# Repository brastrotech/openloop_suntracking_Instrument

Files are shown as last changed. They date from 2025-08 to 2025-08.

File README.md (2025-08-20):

# openloop_suntracking_Instrument
Open-loop sun tracking platform using Raspberry Pi Pico (MicroPython) and Arduino Uno (C++). Calculates sun position via GPS and astronomical algorithms for automated sun-photometer alignment. Includes code, wiring, and sensor integration.

# Open-Loop Sun Tracking Instrument

This project implements an open-loop sun tracking platform using Raspberry Pi Pico (MicroPython) and Arduino Uno (C++). It automatically calculates and aligns a sun-photometer to the sun for atmospheric or AOD studies.

## Features

- **Real-time sun position calculation** using GPS data and astronomic algorithms
- **Dual microcontroller architecture**: Pico handles GPS and sun position; Arduino manages motion and stabilization
- **Servo motor control** for pan/tilt alignment
- **IMU feedback** for basic correction (open-loop)

## Hardware

- Raspberry Pi Pico (RP2040)
- Arduino Uno
- GPS module (NEO-6M / 7m /8m)
- IMU sensor (MPU6050)
- Servo motors (e.g., MG995)
- Power: 5V regulated (e.g., LM2596, 10,000mAh Li-ion packs)

## Code Structure

- `pico_gps_suntracker.py` — MicroPython program for Pico
- `arduino_suntracker.ino` — Arduino code for Uno

## Wiring

- Pico UART TX/RX <-> Arduino UART RX/TX (with proper voltage matching if needed)
- GPS to Pico UART1
- MPU6050 to Arduino (I2C)
- Servos to Arduino PWM pins

## Usage

1. Upload each code file to its respective platform.
2. Assemble hardware per schematic in documentation.
3. On power-up, system will auto-align to the sun based on GPS and real-time computation.

---

**For circuit diagrams, theory, and advanced notes, refer to the `Design-and-development-of-openloop-suntracking-instrument.pdf` file in this repo.**

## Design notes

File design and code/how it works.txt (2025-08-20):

hey guys Yogeshkumar A. patel here
i tried to make solar tracker based on accelerometer (my work on magnetometer still in progress)
over all it is my master's report on my work of 12 months (obviously i did not work contineously as i studied). I personally used lot's of the sensors ,motors , modules ,boards my report of my project is not just how i make it all but also why make it with that component .

let's set it up!!!

1) take one arduino as shown in image here we use arduino as a mster which get the data using uart from raspberry pi pico (data means outout of the solar tracker algorithm inthe form of azuimuth and elevation  ) and using the data of the accelerometer it gives us the pitch roll which we can take as the azimuth and elevation after giving some of the calibration ....
here pitch and roll gives us two kind of banifites 1st is the we can know the data of the where the sun is and second is about to make the whole system stable ( gimbal ) here we can add gyroscope also but over all the data fusion given by that system will be more accurate as well as complex which directly affects over response time of overall system. here we use very low power boards so over all our power consumption will be lesser but it comes with certain limitation of computation power .

2)do  the same thing with the raspberry pi pico 2040 (please make sure that rspberry pi pico had all necessarry files ) check all files and collection use fake files to check the code and result you can compare the result with the website "https://gml.noaa.gov/grad/solcalc/" (the algorithm thanks to this web site "https://levelup.gitconnected.com/python-sun-position-for-solar-energy-and-research-7a4ead801777")

3)i intigrate gps with that system and communicate with uart please make sure that i choose pins according to my boards please make sure the discription of your board and connect the pin accordingly.

4) calibration of the whole system can be achived by set the both motors at 0 angle and mke them to look at the north direction we also need to check that sensor should mount on the right way

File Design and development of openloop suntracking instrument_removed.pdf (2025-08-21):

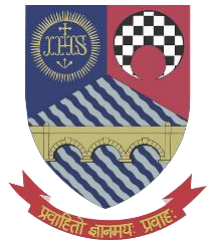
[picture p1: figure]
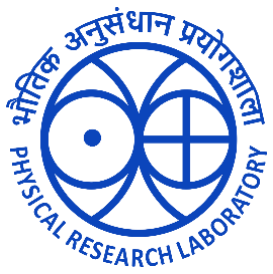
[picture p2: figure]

# DESIGN AND DEVELOPMENT OF OPEN-LOOP SUN TRACKING INSTRUMENT

This research project is accomplished, with affiliation to

### Physical Research Laboratory

By,

Yogeshkumar Patel

In the partial fulfillment of the requirements for the degree

Masters of Science in Physics

(St. Xavier’s College, Ahmedabad)

Under the guidance of

Dr. Harish Gadhavi

Space and Atmospheric Sciences Division

Physical Research Laboratory, Navrangpura Campus– Ahmedabad

Jan 22’ - Apr 23’

# Declaration

I hereby declare that this written submission represents my own work in my own words and where others’ ideas or words have been included, I have adequately cited and referenced the original sources. I also declare that I have adhered to all principles of academic honesty and integrity and have not misrepresented or fabricated or falsified any idea/data/fact/source in my submission. I understand that any violation of the above can cause disciplinary action by the Institute and can also evoke penal action from the sources which have thus not been properly cited or from whom proper permission has not been taken when needed.

Yogeshkumar A. Patel

Date: _______________

# Acknowledgments

I am very thankful to my mentor Dr. Harish Gadhavi, scientist at Physical Research Laboratory, Navrangpura - Ahmedabad for encouraging me greatly in my learning phase and guiding me for the project.

I am very grateful to Mr. Malaidevan, Physical Research Laboratory, Navrangpura- Ahmedabad for always helping me solve my queries and motivating me to keep moving forward.

I would also like to thank Dr. Rajesh Iyer, Head of the Department of Physics-Electronics, St. Xavier’s College, and Mr. Tejas Turakhia for always encouraging me and providing support whenever required for this project.

I would like to thank Parth Dineshkumar Patel for his support in the related software-related guidance.

I am also very thankful to my parents who have always believed in me throughout this journey and have always provided me their great support and encouragement which has constantly pushed me further to cross my limits and to give my best to achieve new things.

# Abstract

Aerosol optical depth (AOD) is an important measure of the amount of aerosols, such as dust, smoke, and pollution, in the Earth's atmosphere. It is defined as the amount of light that is absorbed or scattered by aerosols in the atmosphere, relative to the amount of light that would be transmitted through a clear atmosphere. AOD has several important implications for climate and environmental studies. Sun-photometer is required to estimate AOD which in turn requires it to be pointed toward Sun. We have the sun photometer which can be pointed toward Sun manually but for automated operation and to make observations from a platform such as a balloon or ship, an automated sun-tracker is required. We have tried to make a modular platform for the sun tracker which can take the readings automatically. For this purpose we used microcontroller boards Raspberry pi pico as well as Arduino UNO and for the programming purpose we used two different languages first is C++ and second is Micropython. The sun-tracker included sensors and devices such as Li-Ion cells, Buck converter, GPS, Servo motors, Accelerometer modules, etc. We aim to make a sun tracker for Sun-photometer which is having a field of view of 2.5º.

## Table of Contents

# Introduction

An essential metric for measuring how much an atmospheric aerosol affects weather, climate, and quality of air is called aerosol optical depth (AOD). The ratio of the amount of solar radiation scattered and absorbed by aerosol particles to the amount of solar radiation that would be scattered and absorbed if the atmosphere were entirely clean is known as the aerosol optical depth, or AOD [1] .
A sun tracker instrument is necessary to correctly measure AOD. Sun trackers are gadgets that measure the quantity of direct and dispersed sunlight reaching the ground by tracking the sun's position in the sky throughout the day. Sun trackers are equipped with a solar sensor that monitors the strength of solar radiation and a motorized mount that rotates the sensor to keep it aimed at the sun [2]. Suntracker data can be utilized to calculate the AOD by monitoring the difference between direct and dispersed solar radiation [3]
. Sun trackers are widely utilized in a variety of applications, including air quality monitoring, climate research, and weather forecasting [4]

AOD is a critical measure for determining the effect of atmospheric aerosols on climate change, weather patterns, and human health. Aerosols are microscopic particles floating in the atmosphere that can be solid or liquid and can come from both natural and man-made sources. By reflecting or absorbing sunlight, these particles can have a major influence on the Earth's energy balance, changing the quantity of solar radiation reaching the Earth's surface [5]. The quantity of solar radiation scattered and absorbed by aerosol particles is computed as the ratio of the amount of solar radiation scattered and absorbed if the atmosphere were fully clean [1]. The higher the AOD value, the more aerosols there are in the atmosphere and the greater their influence on climate change and air quality. AOD is commonly measured at various wavelengths using special devices such as sunphotometers or lidars [6]
. Sun trackers are essential for monitoring AOD because they offer reliable readings of direct and dispersed sunlight throughout the day. Sun trackers come in a variety of configurations, including single- and dual-axis models, and are used to follow the sun's passage across the sky [2]. A single-axis sun tracker tracks the sun's daily movement from east to west, whereas a dual-axis sun tracker tracks the sun's elevation angle [7]. Because the amount of dispersed light in the atmosphere fluctuates with the location of the sun and changes during the day, this sort of equipment is required [8]. AOD is measured using a variety of approaches, including satellite-based observations, ground-based sunphotometers, and lidars [9]. Each strategy has advantages and limitations, and the method used is determined by the unique application and data needs [10]
. Sun trackers are crucial for reliable ground-based AOD measurements, especially in densely populated regions with high levels of air pollution, where the amount of dispersed light can be significantly greater than in rural settings [11] .
Sun trackers are used for a number of purposes, such as air quality monitoring, climate research, and weather forecasting. AOD measurements can assist identify the origins of air pollution, estimating the impact of wildfires, and tracing the movement of dust and smoke plumes in air quality monitoring [12]. AOD observations may be utilized in climate research to investigate the influence of aerosols on the Earth's energy balance, cloud formation, and precipitation patterns

[13]
. AOD measurements in weather forecasting can assist enhance the accuracy of short-term weather predictions as well as identify the presence of fog or haze, which can impair aviation safety [14]

Finally, Aerosol Optical Depth is an important measure for determining the influence of atmospheric aerosols on air quality, climate, and weather patterns. Sun trackers, which follow the sun's position in the sky and measure the quantity of direct and dispersed sunlight reaching the ground, are required for reliable AOD readings. Sun trackers are widely utilized in a variety of applications, including air quality monitoring, climate research, and weather forecasting. Further study is needed to better understand the influence of atmospheric aerosols on climate change and human health, as well as to create novel AOD measurement technology.

# Theory

Greenwich Mean Time is the yearly average (or 'mean') of the time each day when the Sun crosses the Prime Meridian at the Royal Observatory Greenwich. So from that we can know about the universal time or GMT (as there is no difference between that).

greenwicℎtime = ℎour − timezone + (

minute
60 ) + (

second
3600 )

From that we got GMT or UT the second quantity is day number here we calculate according to below equation

daynum = 367 ∗ year −

7 ∗ year +

montℎ + 9
12
4

+ 275 ∗ (

montℎ
9

) + day − 730531.5

+

greenwicℎtime
24
here day number is calculated according to the above equation. The term (M+9)/12 in the formula for the Julian Day Number is used to adjust the calculation for the fact that the year in the Julian calendar starts on March 25th, not January 1st as it does in the Gregorian calendar which is the calendar system in use today.

The factor of 275*month/9 is used to account for the varying rate at which the Sun moves along the ecliptic throughout the year. Here 730531.5 is the day number of 1st January, 2000 (J2000) for the reference of the J2000.

Latitudes are horizontal lines that measure the distance north or south of the equator. Longitudes are vertical lines that measure east or west of the meridian in Greenwich, England. We can estimate the sun’s mean longitude it means the geocentric celestial longitude which the sun would have if its apparent annual motion in the ecliptic were at a uniform average or mean angular velocity.

meanlongitude = daynum ∗ 0.01720279239 + 4.894967873

mean longitude of the sun can be get by this equation here 4.894967873 represent the longitude at the J2000 and 0.01720279239 represents the mean daily motion of the sun along ecliptic.

In celestial mechanics, the mean anomaly is a parameter that describes the position of a planet or other celestial object in its orbit around the Sun. It is defined as the angle between the perihelion (the closest point in the orbit to the

Sun) and the current position of the object, measured concerning the center of the elliptical orbit.

meananomaly = daynum ∗ 0.01720197034 + 6.240040768

Here 0.01720197034 is the term that represents the daily motion of the sun in its orbit in radiance. Here 6.2400407680 is the corresponding anomaly to j2000.

The sun's ecliptic longitude is defined as the angle subtended at the earth between the vernal equinox and the sun.

Eclipticlongitude
= meanlongitude + 0.03342305518 ∗ sin(meananomaly) + 0.0003490658504 ∗ sin (2 ∗ meananomaly)

Here 0.03342305518 represents the longitude of the ascending node of the lunar orbit on January 1, 2000.

the obliquity of the ecliptic is the tilt of the earth’s axis of spin as measured from the plane of the ecliptic this angle is about 0.409 radiance and it changes every day due to various factors such as gravitational interactions with other celestial bodies and the precession of the Earth's axis.

Obliquity = 0.409877234 − 6.981317008 ∗ 10⁻⁹ ∗ daynum

The right ascension of a celestial object is a measure of its position in the sky relative to the vernal equinox, which is the point on the celestial sphere where the ecliptic intersects the celestial equator at the beginning of spring in the Northern Hemisphere.

ascension = tan⁻¹ (cos
(Obliquity) ∗ sin(Eclipticlongitude) cos(Eclipticlongitude)

)

Declination is an astronomical term that refers to the angular distance of a celestial body north or south of the celestial equator. The celestial equator is an imaginary line on the celestial sphere that represents the projection of the Earth's equator into space. Declination is measured in degrees, minutes, and seconds of arc, and it is used to locate celestial objects in the sky relative to the celestial equator.

Declanation = sin⁻¹
(sin(Obliquity) ∗ sin(Eclipticlongitude))

Sidereal time is a system of timekeeping used by astronomers to measure the position of celestial objects in the sky. It is based on the rotation of the Earth on its axis relative to the stars, rather than relative to the Sun as in solar time.

Hourangle = Siderealtime − ascension

Coordinates of the sun can be given by the following equations

Elevation = sin⁻¹
(sin(Declanation) ∗ sin(observer

′
slatitude) + cos(Declanation) ∗ cos(observer

′
slatitude) ∗ cos(Hourangle))

Azimutℎ = tan⁻¹

(−cos(Declanation) ∗ cos(Observerslatitude) ∗ sin(Hourangle)) (sin(Declanation) − sin(Observer

′slatitude) ∗ sin(Elevation))

Here the values of Azimuth and Elevation are in radiance.

# Instrumentation

To track the sun using an open loop algorithm, one needs the date, time and coordinates of the device Which we aimed to obtain using GPS. We used microcontroller board named Raspberry Pi Pico 2040 which works on Firmware MicroPython v1.19.1 to process the GPS data.

The Raspberry Pi Pico 2040 which is a microcontroller board designed by the Raspberry Pi Foundation, is based on the RP2040 microcontroller, which is a dual-core Arm Cortex-M0+ processor with 264KB of RAM. The board also features 26 GPIO pins, including 3 analog input pins, a programmable LED, and various other features.

The 26 GPIO pins on the Pico 2040 are labeled GP0 to GP25 and can be used for digital input or output. These pins can be configured as either INPUT or OUTPUT and can also be used for PWM, interrupts, and other functions. Additionally, three of these pins (GP26, GP27, and GP28) can be used for analog input, allowing the Pico 2040 to read analog voltage levels between 0 and 3.3 volts. The analog voltage input is converted into a digital value using a 12-bit ADC built into the RP2040 microcontroller.

The Pico 2040 features a clock frequency of 133 MHz, which is significantly faster than the 16 MHz clock frequency of the Arduino Uno. This means that the Pico 2040 can perform operations and execute instructions much more quickly than the Uno. However, the higher clock frequency also means that the Pico 2040 may consume more power and generate more heat than the Uno.

The Pico 2040 also includes a variety of other features, including a programmable LED connected to GP25, a reset button, and various power and ground pins. The board can be powered by a USB-C connector, and it can also be programmed and powered through its SWD (Serial Wire Debugging) port.

One of the unique features of the Pico 2040 is its support for MicroPython and CircuitPython, which are high-level programming languages designed for microcontrollers. These languages allow developers to write code in Python, which is a popular and easy-to-learn programming language. The Pico 2040 also supports C and C++ programming languages, making it a versatile platform for a wide range of projects.

Here's a brief overview of the pins on the Raspberry Pi Pico:

There are 26 GPIO pins in total, labeled GPIO0 to GPIO25, that can be configured for various purposes, such as digital input/output, analog input, and PWM.

There are three analog pins on the Raspberry Pi Pico: GP26, GP27, and GP28. These pins can be used as analog inputs to read voltages from sensors and other analog devices.

UART is a serial communication protocol that allows two devices to communicate with each other. The Raspberry Pi Pico has two UART interfaces: UART0 and UART1. The pins for UART0 are GP0 (TX) and GP1 (RX), while the pins for UART1 are GP4 (TX) and GP5 (RX).

I2C is a serial communication protocol that allows multiple devices to communicate with each other using only two wires. The Raspberry Pi Pico has two I2C interfaces: I2C0 and I2C1. The pins for I2C0 are GP8 (SDA) and GP9 (SCL), while the pins for I2C1 are GP16 (SDA) and GP17 (SCL).

SPI is a serial communication protocol that allows high-speed data transfer between devices. The Raspberry Pi Pico has two SPI interfaces: SPI0 and SPI1. The pins for SPI0 are GP10 (MOSI), GP11 (MISO), and GP12 (SCK), while the pins for SPI1 are GP19 (MOSI), GP20 (MISO), and GP21 (SCK).

There are several other pins on the Raspberry Pi Pico that can be used for various purposes, including PWM, interrupt handling, and more. These pins include GP2, GP3, GP6, GP7, GP13 to GP15, GP18, GP22 to GP25, and RUN.

The temporal resolution of the Raspberry Pi Pico 2040 depends on the specific application and how it is programmed. The RP2040 microcontroller has a built-in timer system that can be configured to generate interrupts at specific intervals. The timer system can be used to measure time intervals, generate pulses, or trigger events based on specific time conditions.

The Pico 2040's clock frequency of 133 MHz allows for very precise timing, with a maximum resolution of approximately 7.5 nanoseconds per clock cycle. This means that the microcontroller can perform many operations and execute many instructions in a very short amount of time, allowing for high-speed applications.

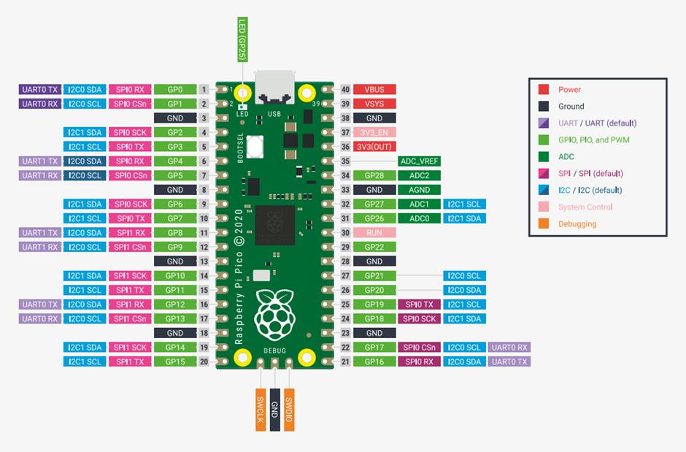
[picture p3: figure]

However, the temporal resolution of the Pico 2040 is ultimately determined by the programming language and algorithms used to control the microcontroller. For example, if the microcontroller is programmed to read a sensor value at a specific rate, the temporal resolution will depend on how accurately the timer system can be configured to trigger the sensor readings.

In general, the Pico 2040 is capable of high-speed and high-precision timing, making it well-suited for applications that require accurate timing or fast data acquisition. However, achieving optimal temporal resolution requires careful programming and configuration of the microcontroller's timer system.

GPS, or Global Positioning System, is a satellite-based navigation system that provides location and time information anywhere on or near the Earth where there is an unobstructed line of sight to four or more GPS satellites.

The GPS system consists of a network of at least 24 satellites orbiting the Earth, as well as ground control stations and GPS receivers. Each satellite broadcasts a signal containing information about its location and the current time. GPS receivers on the ground receive these signals and use the information to calculate their location and time.

To determine its location, a GPS receiver compares the time the signals were transmitted by the satellites with the time the signals were received. The time

Fig 1 :- Pin diagram of raspberry pi pico 2040 difference between when the signal was transmitted and when it was received gives the GPS receiver an estimate of the distance to each satellite. By combining the distances to at least four satellites, the GPS receiver can then calculate its location using a process called trilateration.

The GPS system also uses a technique called "differential GPS" to improve accuracy. This involves comparing the GPS signal from a stationary receiver at a known location with the GPS signal from a mobile receiver. The difference in the two signals can be used to correct errors in the GPS signal caused by atmospheric effects and other factors.

Overall, GPS is an incredibly useful technology that has a wide range of applications, from navigation and surveying to tracking and monitoring.

The GPS NEO 6M is a common GPS module used in many applications, such as drones, robotics, and navigation systems. The NEO 6M module works by receiving signals from GPS satellites and processing them to determine the user's location.

The NEO 6M module has a built-in receiver chip that is capable of receiving signals from up to 22 GPS satellites simultaneously. The module also includes an onboard microcontroller that processes the satellite data and provides a variety of output formats, including NMEA, binary, and u-blox.

The NEO 6M module communicates with a microcontroller or other host device using a serial interface and provides information such as latitude, longitude, altitude, speed, and time. The module also includes a backup battery that allows it to retain satellite data and provide faster location fixes upon power-up.

The NEO 6M module is known for its low power consumption, making it suitable for use in battery-powered applications. It is also relatively easy to use, with a simple command set that allows users to configure the module for their specific application. Overall, the NEO 6M is a popular and reliable GPS module that is widely used in many different types of projects.

Here we got the position of the sun but that data will be inside the Raspberry Pi Pico for transmitting this data to the Arduino Uno we need to establish communication between both of them here are the details about Arduino Uno.

Arduino Uno is a popular open-source microcontroller board designed for easy prototyping of electronic projects. It is based on the ATmega328P microcontroller and has 14 digital input/output pins, 6 analog inputs, and a 16 MHz quartz crystal oscillator.

Here's | a | breakdown | of | the | pins | on | the | Arduino | Uno:

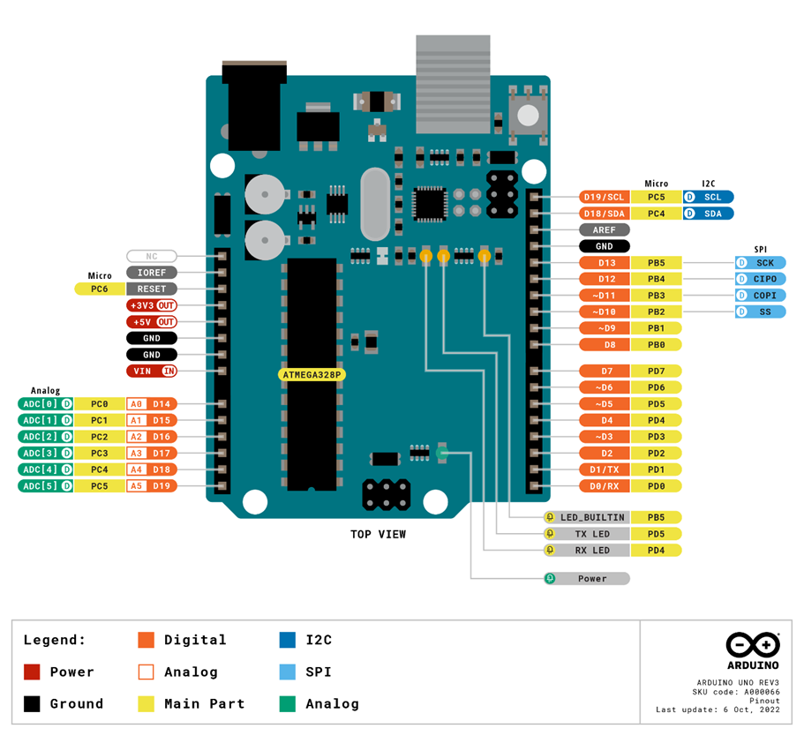
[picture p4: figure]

Digital pins (D0-D13): These are general-purpose input/output (GPIO) pins that can be used for digital input or output. They can be configured as either INPUT or OUTPUT and can also be used for PWM (pulse width modulation) and interrupts. D0 and D1 are also used for serial communication (RX and TX, respectively).

Analog pins (A0-A5): These are analog input pins that can read analog voltage levels between 0 and 5 volts. They can also be used as digital input/output pins (A0 is equivalent to D14, A1 is equivalent to D15, and so on).

Power pins: The Arduino Uno has several power pins, including a 5V pin that can provide up to 500mA of current, a 3.3V pin that can provide up to 50mA, and a Vin pin that can be used to power the board using an external power source (6-20V DC).

Fig 2 :- Pin diagram of Arduino Uno

Ground pins: The Arduino Uno has several ground pins that are connected to the board's ground plane.

Reset pin: This is a special pin that can be used to reset the microcontroller.

ICSP header: This header provides access to the ATmega328P's SPI (Serial Peripheral Interface) pins, which can be used for programming and debugging the microcontroller.

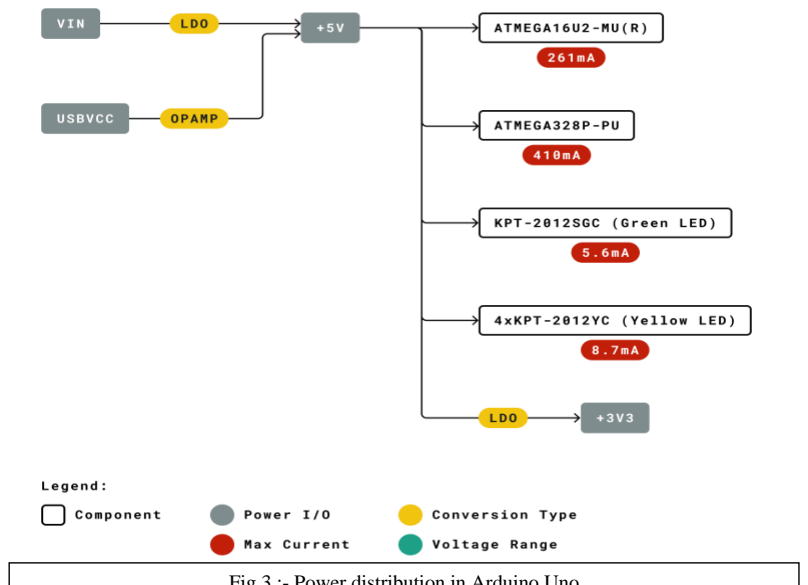
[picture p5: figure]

AREF pin: This pin can be used to set the analog reference voltage used by the analog inputs.

In addition to the above pins, the Arduino Uno also has a built-in LED connected to pin 13, which can be used for debugging and simple output. The board also has a USB connector that can be used for programming and power, as well as a barrel jack connector for external power.

Analog pins on the Arduino Uno are input pins that can read analog voltage levels between 0 and 5 volts. These pins are labeled A0 to A5 and can also be used as digital input/output pins, with A0 equivalent to D14, A1 to D15, and so on.

Analog pins on the Arduino Uno work by converting an analog voltage input into a digital value. This is done using an analog-to-digital converter (ADC) built into

Fig 3 :- Power distribution in Arduino Uno the microcontroller. The ADC samples the voltage at the analog pin and converts it into a digital value, which can then be read by the microcontroller.

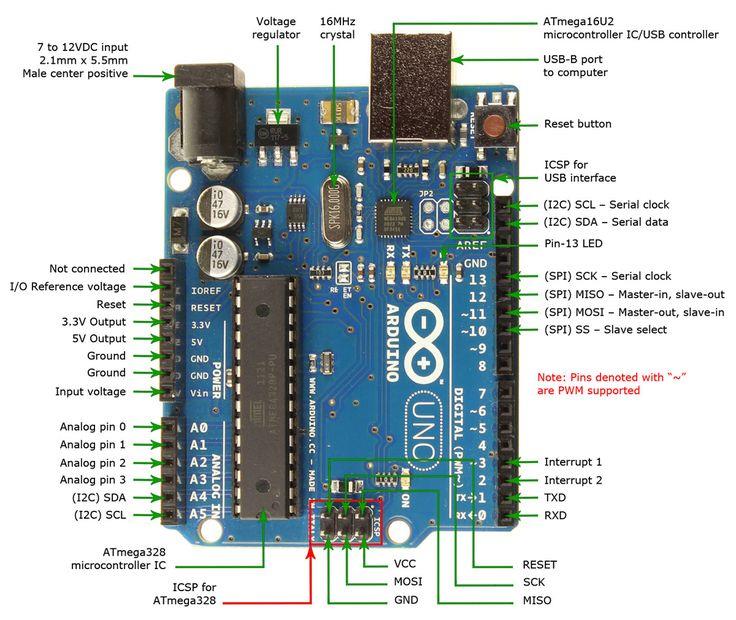
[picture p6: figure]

The resolution of the ADC on the Arduino Uno is 10 bits, which means it can represent analog values from 0 to 5 volts with a resolution of 1024 (2^10). This resolution determines the smallest change in voltage that can be detected by the analog pins. For example, if the voltage range is divided into 1024 steps, each step represents a change of 0.00488 volts (5V / 1024).

To use the analog pins on the Arduino Uno, you can use the analogRead() function in the Arduino IDE. This function reads the analog value from the specified analog pin and returns a value between 0 and 1023. The value returned by analogRead() can be mapped to the desired range of values using the map() function.

Analog pins can be used for a variety of applications, such as reading sensors that output analog voltages, or controlling analog devices such as motors and lights with PWM.

Fig 4 :- Pin diagram of Arduino Uno

Clock frequency, also known as clock speed, refers to the rate at which a processor or microcontroller's clock generates pulses. These pulses are used to synchronize the operation of various components within the processor or microcontroller.

In the case of the Arduino Uno, the clock frequency is 16 MHz, which means the clock generates 16 million pulses per second. This clock frequency determines how quickly the microcontroller can perform operations and execute instructions.

A higher clock frequency generally means that the microcontroller can perform operations more quickly and execute more instructions per second. However, a higher clock frequency also means that the microcontroller may consume more power and generate more heat.

In some cases, it may be necessary to adjust the clock frequency of the microcontroller to optimize performance or reduce power consumption. This can be done using various techniques, such as changing the clock divider settings or using an external oscillator. However, modifying the clock frequency can also affect the operation of the microcontroller, so it should only be done with caution and with a thorough understanding of the system.

Overall, the clock frequency is an important parameter to consider when designing and programming systems based on microcontrollers like the Arduino Uno. It can have a significant impact on the performance and power consumption of the system and should be carefully considered during the design process.

Here Arduino works with one main sensor module named mpu-6050 here other options are also available like bmx 160, Adxl 345 .

Here Adxl345 sensor’s stability analysis is shown in the graph as shown in the graph it is stable with the time as well as on board low pass filter is there that’s why the filtered output is much more smoother than the basic one.

The second sensor is mpu6050 which is 3 axis gyroscope and 3-axis accelerometer sensor module this module contains a complimentary filter (DMP) inside a module which give us the upper hand in the digital motion process than

Adxl345.

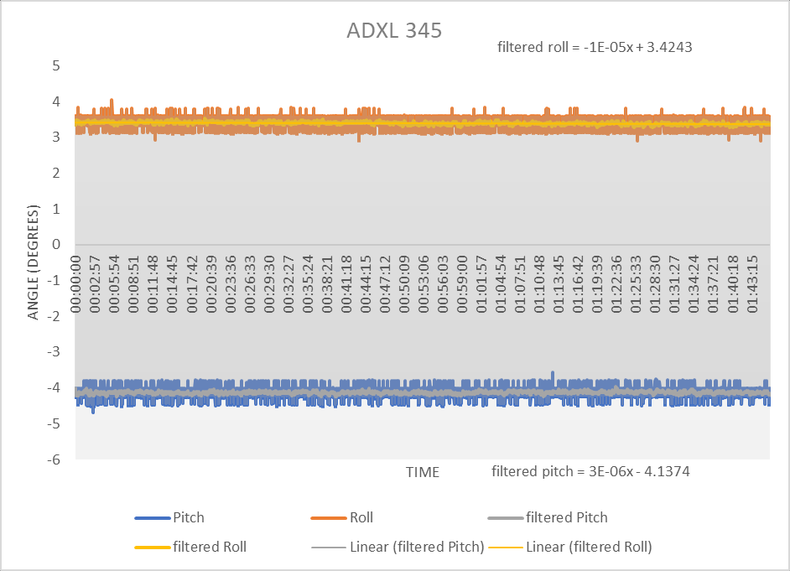
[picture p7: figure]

Here we took readings every second so we got total of 2224 readings for stability analysis over the constant angle here with the use of complementary filter we got a slope of 0.0001 which can be neglected with the use of the Kalman filter our slope will be more accurate approximately 0.00004 which is good but it comes with the price of higher computation power requirement as well as it needs more complex codes also which will end up with more complexity over the system here raw data from the sensor but complimentary filtered values are nearly same and nearly unchanged over a time same for y-axis also which makes it perfect sensor to get the angle values. both graphs are shown in the figure

Here to use this angle we used Servo motors which take inputs as a PWM(Pulse Width Modulus) which can be done by using Raspberry Pi Pico or Arduino Uno

Fig 5 :- Stability analysis Of Adxl345 Sensor module

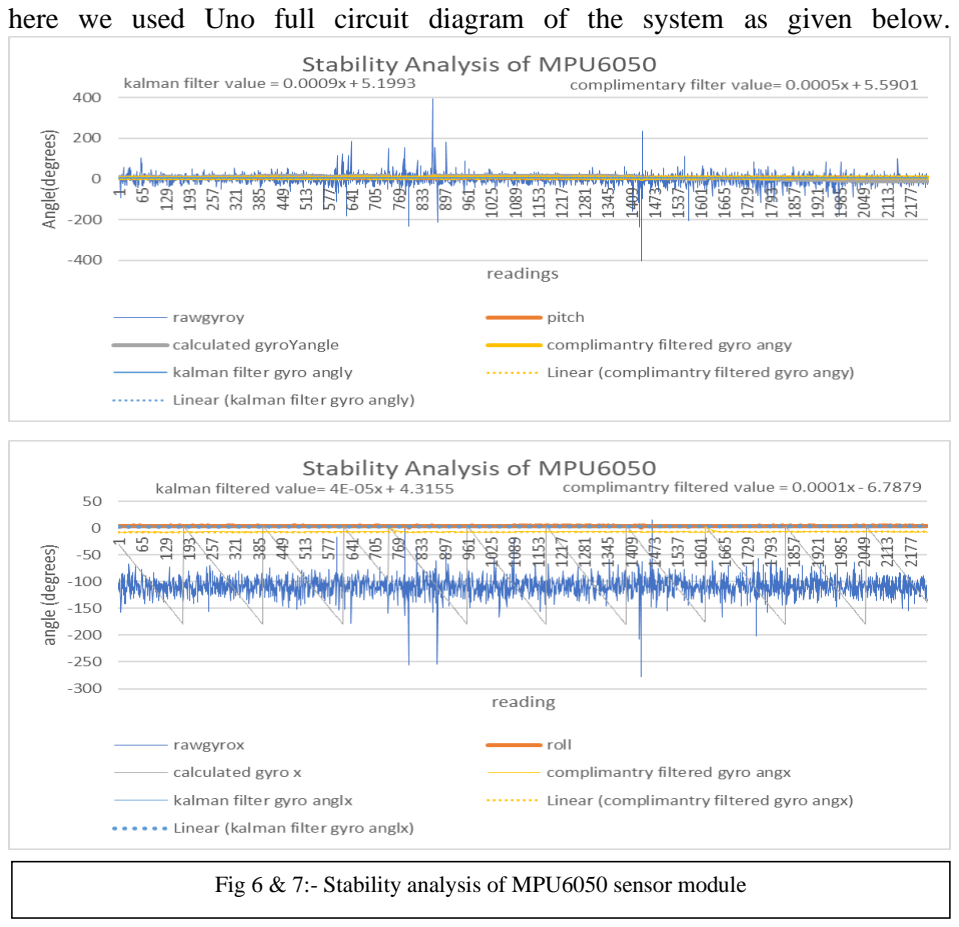
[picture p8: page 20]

here we used Uno full circuit diagram of the system as given below.

Fig 6 & 7:- Stability analysis of MPU6050 sensor module

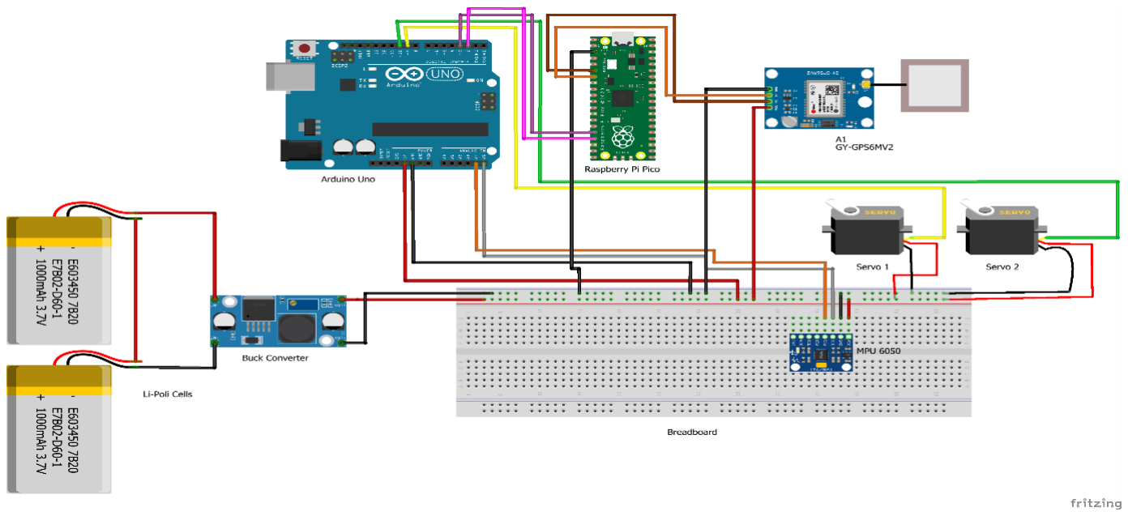
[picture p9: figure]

Here we powered up the whole system by using 2 batteries of 10000 mAh each and the voltage regulator module LM2596 for 5V Regulated voltage here the connection between Raspberry Pi Pico Arduino Uno, GY-GPS6MV2 , MPU6050 as well as Servo connection is also there here we need to care about one thing is that the motors need much more current than any other devices and it will also highly depends upon which motor we are using as well as how much weight we put on the motors which can vary the speed of the motors (for continuous servo ) and it makes one disadvantage over the continuous servo motors but positional servo motors can be used as precise till 1-degree precision . Here is the problem comes here we want to use this platform to track the sun. the sun itself having an angular diameter of 30’ minutes which means(0.5 degrees).

Fig 8 :- circuit diagram of open-loop sun tracking instrument

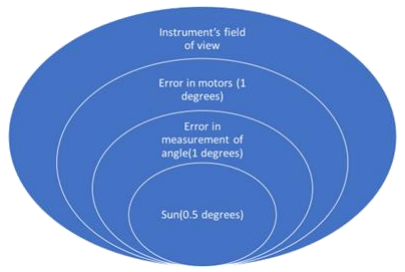
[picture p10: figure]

For the solution we need to take the NA (numerical aperture) of the instrument here we use the sun photometer which has field of view of 2.5 degrees. So, we get that data from the sun rays so that’s how we can get the data for the instruments. suppose we had the error of 1 degree in the measurement of the angle so the total error can increase to 2 degrees since we had the field of view (NA in the case of fibers) we still get the data. Here we had two types of errors.

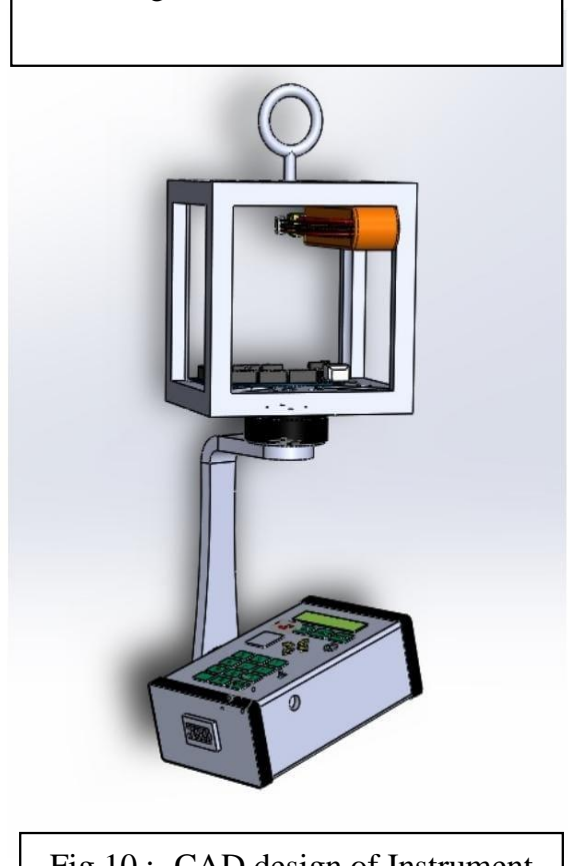
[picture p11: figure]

❖ Error in the measurement of angle: -
- when we are talking about the angle of the measurement it depends upon the imu sensor here our imu sensor gives us some data it can be possible that provided data has errors of 1 degree.

❖ Error in the execution of motor:-
- When we talk about motors we should understand how it works first of all servo motors have an encoder , potentiometer, and motor inside them. all of these make the servo motor precise till 1 degrees rotation but as we know that it is not a very reliable method when temperature varies and it is possible because it contains a resistor that varies with the temperature. The encoder also had its limits. Servo had a lack of smoothness but the gimbal works pretty smoothly. Both of the errors can be adjusted by the use of the gimbal motors and motor drivers. But it can cost us higher power consumption as well as weight also increases. here is some comparison between both of them
| Weight | Power consumption
Servo (MG 995) | 55 gm | 4.8 V , 0.7 A (3.5 W)
Gimbal (GB 54-1) | 137 gm | 4s

Fig 9:- solution for error

Fig 10 :- CAD design of Instrument with gimbal motor

Table 1 :- motor comparison

- Hence Gimbal motors consumed much more power than Servo motors but the smoothness in gimbal motors is unmatched and also they can carry much more load than servo motors as it depends upon how much current we give to the motor.
- Right now we are using servo motors for lower power consumption it also had the advantage of the lower complexity in the code and it didn’t require a motor driver . here is our model which uses gimbal motors for rotation.
- Here the important thing about the angles is the reference (which angle we should take as 0 degrees) here we are use the horizontal coordinate systems of the celestial sphere.
- So that’s why we use north as our reference for Azimuth
Cardinal point | Azimuth
North | 0º
East | 90º
South | 180º
West | 270º
- We use altitude angle from the horizontal plane(it is the angle between the object and the local horizon).

Table 2:- directional references for Azimuth

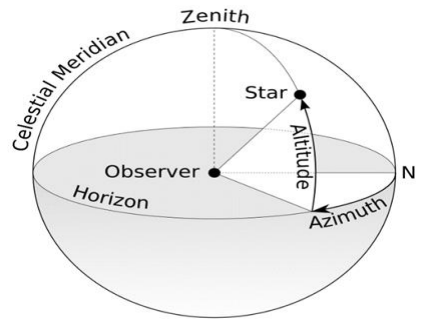
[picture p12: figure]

Fig 11:- horizontal co-ordinate system in celestial sphere

# Result and Conclusion

❖ Here from this method we got accurate coordinates of the sun using the open-loop method(~0.01º precession)[18]

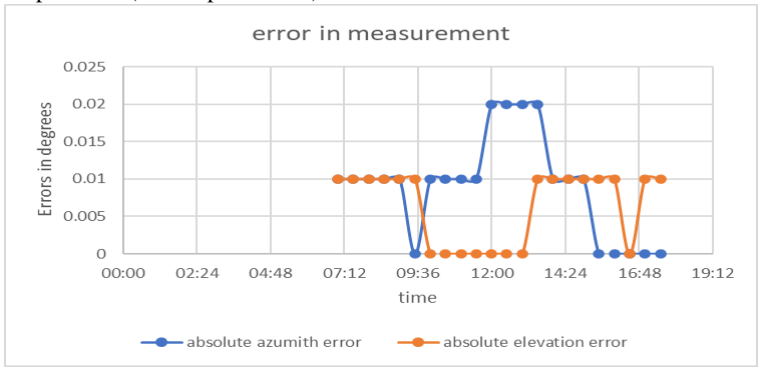
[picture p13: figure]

❖ The method we are using right now is not so sufficient for continuous data collection
❖ As it whole system is made as an open loop system it does have not any kind of feedback here so it makes the method somewhat less precise than close loop systems when we consider external disturbance added in the whole system so it makes the system much unstable for longer period which results into data lose. For that purpose, we uses mpu 6050 (IMU) sensor here ❖ MPU 6050 can work fine with proportional feedback but it is not so smooth transition .
❖ Here we get the settling time of nearly 1 second (using pid tunning) for response time with transient behavior which is not so good because for 1-

Fig 12:- error in measurement

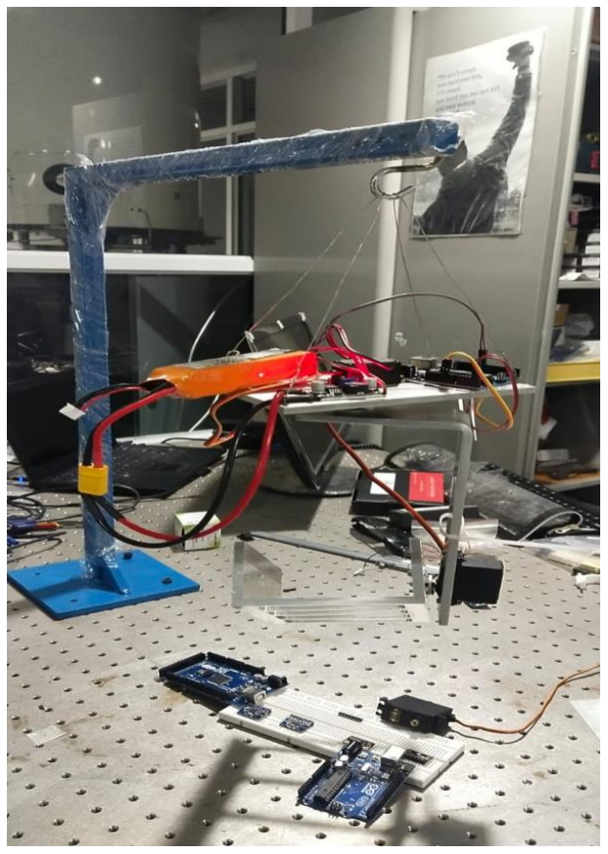
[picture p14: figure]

Fig 13 :- Experimental setup of the instrument second sun can be out of the instrument’s field of view. It results in us data loss or unstable system
❖ As the temperature changes the microcontroller peripheral devices and modules are either getting some sort of error or they can’t work efficiently. ❖ Here mpu6050 does not contain any kind of magnetometer so we need to calibrate in the north direction manually

# Solutions & Future Aspects

❖ continuous data collection can be possible using higher clock frequency microcontrollers and peripheral devices
❖ We can get the 0.1 second response time using an external processor and software work but we need to make that work on standalone also that’s why we need more computational power as well as more efficient and precise motors.
❖ As a platform it needs some sort of cooling system to make sure the temperature variance will not take place as it affects the process as well as the performance of the microprocessor, sensors, and other peripheral devices.
❖ We need to use either a pid system or a model predictive control system based on a system which had higher computation power and higher clock frequency. ❖ We need to change the sensor mpu 6050 with bmx 160 which is 16 bit accelerometer, gyroscope and geomagnetic sensor.

# References

1. Kaufman, Y. J. (1993). The atmospheric effect on solar radiation and atmospheric aerosols. In Advances in Atmospheric Remote Sensing with Lidar (pp. 27-42). Springer, Berlin, Heidelberg.
2. Gueymard, C. A. (2008). Solar radiation and daylight models. Academic Press.
3. Holben, B. N., Eck, T. F., Slutsker, I., Tanre, D., Buis, J. P., Setzer, A., ... & Vermote, E. (1998). AERONET—a federated instrument network and data archive for aerosol characterization. Remote sensing of environment, 66(1), 1-16.
4. Jethva, H., & Satheesh, S. K. (2016). A review of satellite-based aerosol detection techniques for air quality applications. Atmospheric environment, 125, 404-415.
5. IPCC. (2013). Climate change 2013: The physical science basis. Working Group I contribution to the fifth assessment report of the Intergovernmental Panel on Climate Change.
6. Mishra, A. K., Shibata, T., & Matsui, T. (2017). Aerosol optical depth retrieval over land surfaces from AVIRIS-NG using a kernel-driven BRDF model. Remote Sensing, 9(11), 1162.
7. Luria, M., Maman, S., & Sinvani, M. (2013). Design and development of a dual-axis sun tracker with two degrees of freedom. IEEE Transactions on Industrial Electronics, 60(4), 1452-1462.
8. Diner, D. J., Beckert, J. C., Reilly, T. H., Bruegge, C. J., Conel, J. E., Kahn, R. A., ... & Martonchik, J. V. (1998). Multi-angle Imaging SpectroRadiometer (MISR) instrument description and experiment overview. IEEE Transactions on Geoscience and Remote Sensing, 36(4), 1072-1087.
9. Liou, K. N. (2002). An introduction to atmospheric radiation. Academic Press.
10. Dubovik, O., & King, M. D. (2000). A flexible inversion algorithm for retrieval of aerosol optical properties from Sun and sky radiance measurements. Journal of Geophysical Research: Atmospheres, 105(D16), 20673-20696.
11. Holben, B. N. (1986). Characteristics of maximum-value composite images from temporal AVHRR data. International journal of remote sensing, 7(11), 1417-1434.
12. Kumar, K. R., Kumar, N. K., & Reddy, B. S. (2010). Temporal analysis of aerosol parameters over an urban station using ground-based remote sensing. International Journal of Remote Sensing, 31(3), 631-642.
13. Ramanathan, V., Crutzen, P. J., Kiehl, J. T., & Rosenfeld, D. (2001). Aerosols, climate, and the hydrological cycle. Science, 294(5549), 2119-2124.
14. Devidal, J. L., & Boucher, O. (2002). Retrieval of the aerosol optical thickness using ground-based measurements of solar radiation at two different altitudes. Journal of Geophysical Research: Atmospheres, 107(D24), ACH 8-1-ACH 8-15.
15. Britannica, T. Editors of Encyclopaedia. "celestial coordinates." Encyclopedia Britannica, February 20, 2018. https://www.britannica.com/science/celestial-coordinates.
16. Datasheet of adxl,mpu6050,Arduino uno, raspberrypi pico, bmx 160 , neo gps 6m, voltage regulator , servo mg 995
17. John Clark Craog ,Sun Position: Astronomical Algorithm in 9 Common Programming Languages, May 31,2017 , ISBN-13 978-1546576259, ISBN-10 1546576258
18. NOAA solar calculator ,Global monitoring laboratory (https://gml.noaa.gov/grad/solcalc/)

# Code

from machine import Pin, UART, SoftI2C

import utime, time

gpsModule = UART(1, baudrate=9600)

print(gpsModule)

buff = bytearray(255)

TIMEOUT = False

FIX_STATUS = False

latitude = ""

longitude = ""

satellites = ""

GPStime = ""

h = ""

m = ""

s = ""

def getGPS(gpsModule):

global FIX_STATUS, TIMEOUT, latitude, longitude, satellites, GPStime

timeout = time.time() + 8

#gpsModule.readline()

#buff = str(gpsModule.readline())

#print(buff)

while True:

gpsModule.readline()

buff = str(gpsModule.readline())

#print(buff) #debug

parts = buff.split(',')

if (parts[0] == "b'$GPGGA" and len(parts) == 15):

if(parts[1] and parts[2] and parts[3] and parts[4] and parts[5] and parts[6] and parts[7]):

print(buff)

latitude | | | =
convertToDegree(parts[2])

if (parts[3] == 'S'):

latitude = -latitude

longitude | | | =
convertToDegree(parts[4])

if (parts[5] == 'W'):

longitude = -longitude

satellites = parts[7]

h = print(parts[1][0:2])

m = print(parts[1][2:4])

s = print(parts[1][4:6])

GPStime = parts[1][0:2] + ":" + parts[1][2:4] + ":" + parts[1][4:6]

FIX_STATUS = True

break

if (time.time() > timeout):

TIMEOUT = True

break

utime.sleep_ms(1000)

def convertToDegree(RawDegrees):

RawAsFloat = float(RawDegrees)

firstdigits = int(RawAsFloat/100)

nexttwodigits | = | RawAsFloat | -
float(firstdigits*100)

Converted | = | float(firstdigits | +
nexttwodigits/60.0)

Converted = '{0:.6f}'.format(Converted)

return str(Converted)

i=0

while i==0:

i = i+1

getGPS(gpsModule)

if(FIX_STATUS == True):

print("Printing GPS data...")

print(" ")

print("Latitude: "+latitude)

print("Longitude: "+longitude)

print("Satellites: " +satellites)

print("Time: "+GPStime)

print("h"+h)

print("m"+m)

print("s"+s)

print("----------------------")

FIX_STATUS = False

if(TIMEOUT == True):

print("No GPS data is found.")

TIMEOUT = False

# -*- coding: utf-8 -*-

"""

Created on Sun Nov 27 01:51:40 2022

@author: yap21

"""

# sunpos.py

import math

execfile("oncegps.py")

def | gmt_to_ist(gmt_time,
timezone='Asia/Kolkata'):

"""

Converts a given time in GMT format to IST format.

Args:

| gmt_time (str): A string representing the
time in the format 'HH:mm:ss'
| timezone (str): An optional parameter
specifying the timezone to convert to. Defaults to 'Asia/Kolkata'.

Returns:

| str: A string representing the time in the
specified timezone in the format 'HH:mm:ss'

"""

# Define a dictionary of timezone offsets in seconds

timezone_offsets = {

'GMT': 0,

| 'Asia/Kolkata': 19800, # GMT +5:30
(5.5 hours = 19800 sec)
| 'US/Eastern': -18000, # GMT -5:00
| # Add more timezone offsets as needed

}

# Split the input time string into hours, minutes, and seconds

gmt_hours, gmt_minutes, gmt_seconds = map(int, gmt_time.split(':'))

# Calculate the total number of seconds in the input time

gmt_total_seconds = gmt_hours * 3600 + gmt_minutes * 60 + gmt_seconds

# Calculate the time difference between GMT and the target timezone in seconds

timezone_offset | | =
timezone_offsets.get(timezone, 0)

# Calculate the total number of seconds in the target timezone

target_total_seconds = gmt_total_seconds + timezone_offset

# Calculate the hours, minutes, and seconds in the target timezone

target_hours, | target_minutes | =
divmod(target_total_seconds, 3600)
target_minutes, | target_seconds | =
divmod(target_minutes, 60)

# Format the resulting time as a string and return

return
f"{target_hours:02}:{target_minutes:02}:{tar get_seconds:02}"

# Convert a GMT time to IST

GPStime = gmt_to_ist(GPStime)

print("Latitude: "+latitude)

print("Latitude: "+latitude)

print("Longitude: "+longitude)

print("Satellites: " +satellites)

print("Time: "+GPStime)

parts = GPStime.split(":",2)

hour = parts[0]

#hour = int(hour)

minute =parts[1]

#minute = int(minute)

second = parts[2]

latitude = float(latitude)

longitude = float(longitude)

#print("h"+h)

#print("m"+m)

#print("s"+s)

print("----------------------")

#print(buff) #debug

#parts = buff.split(',')

#print("h"+h)

#print("m"+m)

#print("s"+s)

#from datetime import datetime

def sunpos(when, location, refraction):

# Extract the passed data

year, month, day, hour, minute, second, timezone = when

latitude, longitude = location

# Math typing shortcuts

rad, deg = math.radians, math.degrees

sin, cos, tan = math.sin, math.cos, math.tan

asin, atan2 = math.asin, math.atan2

# Convert latitude and longitude to radians

rlat = rad(latitude)

rlon = rad(longitude)

# Decimal hour of the day at Greenwich

greenwichtime = hour - timezone + minute / 60 + second / 3600

# Days from J2000, accurate from 1901 to 2099

daynum = (367 * year - 7 * (year + (month + 9) // 12) // 4 + 275 * month // 9 + day -730531.5 + greenwichtime / 24)

# Mean longitude of the sun

mean_long = daynum * 0.01720279239 + 4.894967873

# Mean anomaly of the Sun

mean_anom = daynum * 0.01720197034 + 6.240040768

# Ecliptic longitude of the sun

eclip_long = (mean_long + 0.03342305518 * sin(mean_anom) + 0.0003490658504 * sin(2 * mean_anom))

# Obliquity of the ecliptic

obliquity | = | 0.4090877234 | -
0.000000006981317008 * daynum

# Right ascension of the sun

rasc | = | atan2(cos(obliquity) | *
sin(eclip_long), cos(eclip_long))

# Declination of the sun

decl = asin(sin(obliquity) * sin(eclip_long))

# Local sidereal time

sidereal = 4.894961213 + 6.300388099 * daynum + rlon

# Hour angle of the sun

hour_ang = sidereal - rasc

# Local elevation of the sun

elevation = asin(sin(decl) * sin(rlat) + cos(decl) * cos(rlat) * cos(hour_ang))

# Local azimuth of the sun

azimuth = atan2( -cos(decl) * cos(rlat) *
sin(hour_ang), | sin(decl) | - | sin(rlat) | *
sin(elevation),)

# Convert azimuth and elevation to degrees

azimuth = into_range(deg(azimuth), 0, 360)

elevation = into_range(deg(elevation), -180, 180)

# Refraction correction (optional)

if refraction:

targ = rad((elevation + (10.3 / (elevation + 5.11))))

elevation += (1.02 / tan(targ)) / 60

# Return azimuth and elevation in degrees

return (round(azimuth, 2), round(elevation, 2))

def into_range(x, range_min, range_max):

shiftedx = x - range_min

delta = range_max - range_min

return (((shiftedx % delta) + delta) % delta) + range_min

if __name__ == "__main__":

# Close Encounters latitude, longitude

location = (latitude, longitude)

hour = int(hour)

minute = int(minute)

second = int(second)

#location = (23.0225, 72.5714)

# Fourth of July, 2022 at 11:20 am MDT (-6 hours)

#when | | | =

(year,month,day,hour,minute,seconds,timezo ne)

#when = (2023, 2, 24, 13, 50, 0, +5.5)

when = (2023, 2, 24, hour, minute, second, 0)

#when = (2023, 2, 22, h, m, s, +5.5)

# Get the Sun's apparent location in the sky

azimuth, | elevation | = | sunpos(when,
location, True)

# Output the results

print("\nWhen: ", when)

print("Where: ", location)

print("Azimuth: ", azimuth)

print("Elevation: ", elevation)

# When: (2022, 7, 4, 11, 20, 0, -6)

# Where: (40.602778, -104.741667)

# Azimuth: 121.38

# Elevation: 61.91

from machine import UART

import time

#from timer import delay

# Set up UART on pins 16 (TX) and 17 (RX) at a baud rate of 115200

uart | = | UART(0, | baudrate=115200,
tx=machine.Pin(12), rx=machine.Pin(13))

print(uart)

# Read a line of data from the UART

#data = uart.readline()

execfile("fakest.py")

uart.write(f' azimuth: {azimuth}')

uart.write(f',Elevation : {elevation}')

uart.write(f' | ')

#uart.write(b"here is the data\n")

while(1==1):

# pass

# Write a line of data to the UART

execfile("fakest.py")

#uart.write(f'{azimuth}')

#uart.write(',')

#uart.write(f'{elevation}')

#uart.write("\n")

uart.write(f'{azimuth},{elevation}')

print(f'{azimuth},{elevation}')

print("sent suc")

time.sleep_ms(1000)

#uart.write("When: ", when)

#uart.write(",where: ", location)

#Alternatively, you can use the uart object as a file-like object

# to read and write data:

#uart.write(b"Hello, world!\n")

# data = uart.readline()

# delay(1)

For Arduino uno we uses c/c⁺⁺ programming language.

/* Get tilt angles on X and Y, and rotation angle on Z

* Angles are given in degrees

* License: MIT

*/

#include "Wire.h"

#include <MPU6050_light.h>

#include <Servo.h>

Servo pitchs;

Servo rolls;

float X,Y,Z,pitch,roll, yaw;

#include <SoftwareSerial.h>

int a0,b0,a,b;

String message ;

SoftwareSerial uart(3, 2);

MPU6050 mpu(Wire);

unsigned long timer = 0;

void setup() {

Serial.begin(115200);

uart.begin(115200);

Wire.begin();

byte status = mpu.begin();

Serial.print(F("MPU6050 status: "));

Serial.println(status);

while(status!=0){ } // stop everything if could not connect to MPU6050

Serial.println(F("Calculating offsets, do not move MPU6050"));

delay(1000);

// mpu.upsideDownMounting = true; // uncomment this line if the MPU6050 is mounted upside-down

mpu.calcOffsets(); // gyro and accelero

Serial.println("Done!\n");

pitchs.attach(9);

rolls.attach(10);}

void loop() {

mpu.update();

String message = uart.readStringUntil('\n');

if((millis()-timer)>1000){ // print data every 10ms

Serial.print("X : ");

X = mpu.getAngleX();

Y = mpu.getAngleY();

Z = mpu.getAngleZ();

String message = uart.readStringUntil('\n');

pitch = 180 * atan2(X, sqrt(Y*Y + Z*Z))/PI; // calculate the pitch angle

pitch = pitch +90; // here 90 is to make the pitch from 0 to 180 insted of -90 to 90 for servo

pitch = pitch + b; // set the angle accordingly your elevation here b is elevaion

roll = 180 * atan2(Y, sqrt(X*X + Z*Z))/PI;

roll = roll + 90; // here 90 is to make the pitch from 0 to 180 insted of -90 to 90 for servo

roll = roll + a; // here a is azimuth

pitchs.write(pitch);

rolls.write(roll);

Serial.println();

Serial.print(pitch);

Serial.print(roll);

timer = millis();

}

}

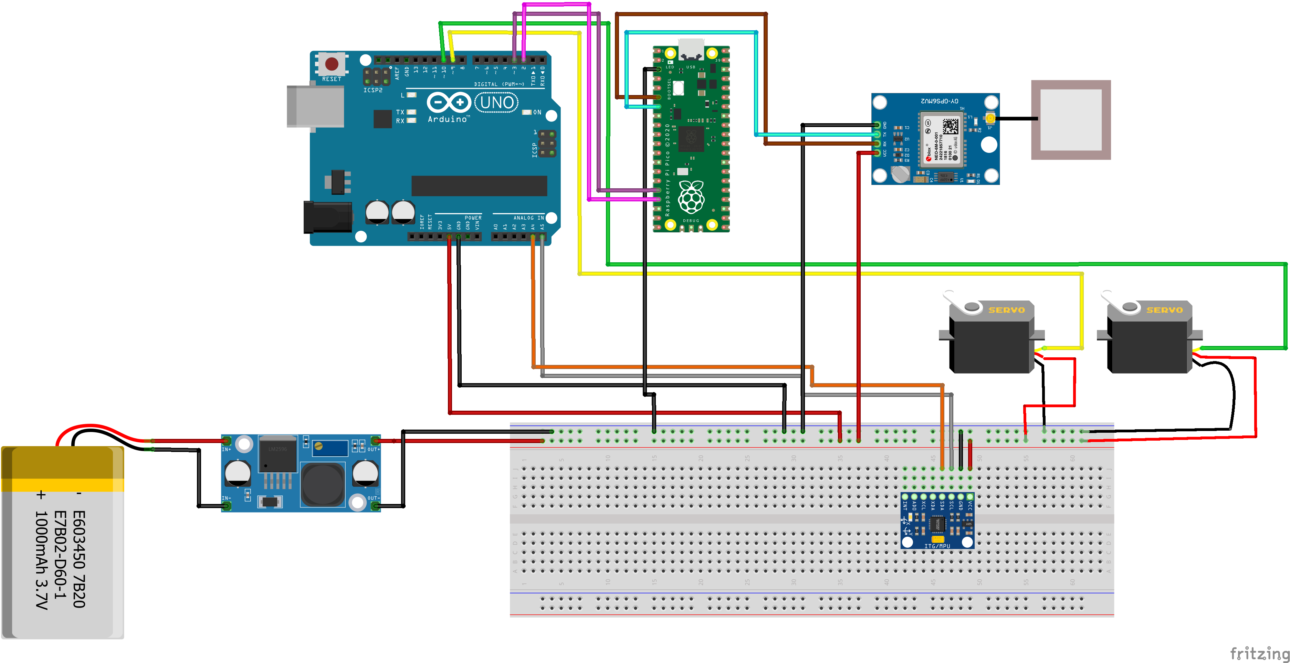
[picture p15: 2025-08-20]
design and code/prlsys_bb.png

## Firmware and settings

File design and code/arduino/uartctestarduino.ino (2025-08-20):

#include <SoftwareSerial.h>


SoftwareSerial uart(3, 2);

void setup() {
  // Open serial communications and wait for port to open:
  Serial.begin(115200);
  uart.begin(115200);
 




 Serial.println("done");
}

void loop() {
  
  String message = uart.readStringUntil('\n');
    

  // if the file opened okay, write to it:   
  while (1==1) {
    while (uart.available()) {
    Serial.write(uart.read());}
    //int message = uart.read();
    /*String message = uart.readStringUntil('\n');*/
    //Serial.println(message);
    /*int a = message.substring(0, message.indexOf(',')).toInt();
    int b = message.substring(message.indexOf(',')+1).toInt();
    Serial.println("Received a = " + String(a) + ", b = " + String(b));*/
    //Serial.println(data);
    
   
    
    //Serial.println("take the data successfully");
    delay(1000);
    
  

  }
  }
  
  
